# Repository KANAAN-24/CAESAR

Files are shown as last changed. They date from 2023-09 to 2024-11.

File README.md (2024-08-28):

# Introduction #

We are the Kanaan team from the Qabatya Directorate of Education of the State of Palestine.
We designed, assembled and programmed the robot, which we called Caesar, to perform the tasks and performance required in preparation for participation in the World Robotics Olympiad (WRO) competition.

# Team members #

Coach's name: Ahmed Mazid Al-Bazour ,
Email: ahmadbzoor48@gmail.com
1) Student name: Hisham Omar Qalalwa ,
Email: hishamqalalwal@gmail.com
2) Student name: Majd Khaled Azzam ,
Email: majoodazzam2@gmail.com

# Content #

* `t-photos` contains 2 photos of the team (an official one and one funny photo with all team members).
* `v-photos` contains 7 photos of the vehicle (from every side, from top and bottom).
* `video` contains the video.md file with the link to a video where driving demonstration exists.
* `schemes` Includes JPEG and PDF diagrams illustrating all car components electromechanic (electronic and others), and their connections.
* `src` contains codes of control software for all components which were programmed to participate in the competition.
* `models` They are files of designs 3D that were printed by two 3D printersTo produce car structure and
its items. 
* `Documentation` This volume covers robot construction, electronic components integration, and software algorithm Explanation about.
* `other` These files pertain to the work environment and work-related events.

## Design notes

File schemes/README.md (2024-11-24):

# Introduction #
Folder contains the electrical design schematics and the mechanic.

# Overview #
- `Main Diagram.jpg` Folder contains the electrical design schematic for the CAESAR Robot.
- `Mechanical Diagram.pdf` Folder contains design schematics the mechanic for the CAESAR Robot, as it is an open source design from the internet, we modified it and made the CAESAR Robot.

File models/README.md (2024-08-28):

# Introduction #
All of these designs were designed and printed by us, and all of them have been used.

# Overview #
+ `Battary` It contains two types of battery holder (the best was used) and its holder.
+ `Camera and Servo` It houses a servo motor holder connected to the steering wheel, a cover for the servo motor, and a camera holder positioned on top.
+ `chassis` It contains two pieces that are brought together to form the car's body and its supports.
+ `Level` A piece for the switch to convert the mode.
+ `Processing` It features a house-like piece that opens and closes with a screw for easy access, revealing a rectangular base for the ESP32 inside.
+ `Stearing` Contains string pieces.
+ `Team` An image of the team’s logo, its name, and a 3D design of the Palestinian keffiyeh.
+ `Ultrasonic` It contains an ultrasonic incubator and its covers.
+ `Wheel` Pieces to connect the wheels to the steering wheel.

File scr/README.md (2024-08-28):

# Introduction #
This directory contains code for control software which is used by the vehicle to participate in the competition and was developed by team KANAAN.

# Overview #
- `Obstacle Challenge Code` Codes for the stage two of the competition in which there are obstacles and The engines and other parts were programmed in C++ and we used Python for Artificial Intelligence.
- `Open Challenge Code` Codes for the first stage, where the engines and the rest of the parts were programmed in the C++ language.

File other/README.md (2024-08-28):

# Introduction #
It contains pictures and files related to work and some situations.

# Overview #
- `3D printers` It contains two pictures of the two 3D printers and their room.
- `Build` The Build contains the step to build a game mat.
- `CAESAR` It contains a file explaining the pieces.
- `Failed` It contains images of 3D designs with errors.
- `KANAAN` It contains a our team logo KANAAN.

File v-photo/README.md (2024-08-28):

# Introduction #
Folder contains photos of the CAESAR from all required directions.

# Overview #
- `Back Side.jpg` Ultrasonic box with battery incubator.
- `Down Side.jpg` A 3D printed base supports the car's steering wheel and various components above it.
- `Front Side.jpg` Ultrasonic incubators feature a wheel carrier to prevent collisions with the mat's outer frame and a camera mount on a 3D cover for the servo motor.
- `Left Side.jpg` Two incubators for controllers and other electronic parts.
- `Right Side.jpg` Incubators for electronic parts with a light indicating the robot's mode at what stage.
- `Top Side1.jpg` Operating button with 3D electronic parts carrier.

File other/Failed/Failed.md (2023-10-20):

# Introduction #
This image is of a 3D design that we printed, but it failed due to a support glitch

# Content #
failed2

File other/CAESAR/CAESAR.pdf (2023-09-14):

# Stages of making a CAESAR

## ENG.AHMAD

## HISHAM

## MAJD

## KANAAN Team

# Introduction

WRO Future Engineers -Selft Driving car
selft driving car

When we talk about competitions that are concerned with the field of robotics, we must talk about The World Robot Olympiad (WRO) , which was launched for the youth category. China, Japan and Singapore, and these four countries are the founding countries of this Olympiad (now known as the WRO Advisory Board).

# Problems

## Our Competition:

We are competing in this competition in the Future Engineers category It revolves around designing a self-driving robot that can overcome the obstacles and problems it encounters in the least possible time, based on artificial intelligence and machine learning.

## Contest idea:

The environment of this competition consists of a circuit surrounded by an external wall, inside which there is an internal wall. As for the competition, it consists of one stage in which the robot runs at a rate of 3 laps that it must complete in .3 minutes as a maximum

## Stage 1:

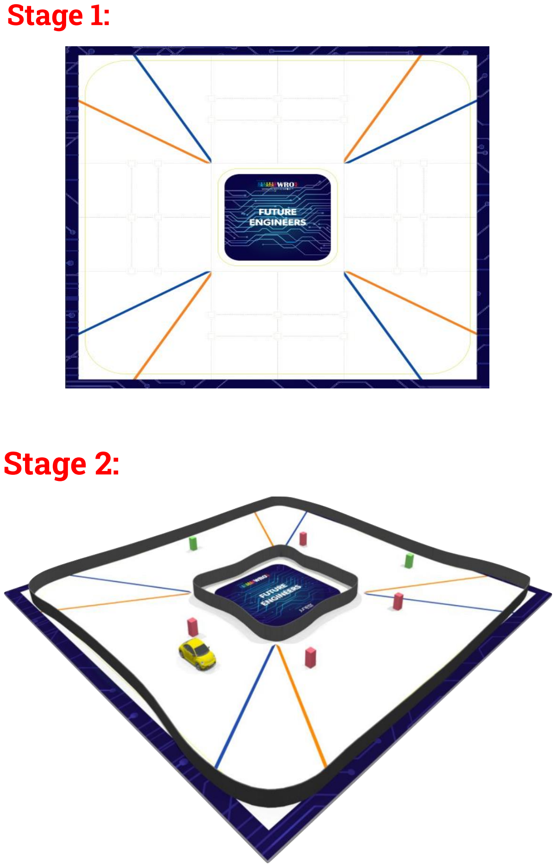
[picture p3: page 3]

# Stage 2:

# Hypotheses

During our work and the manufacture of the robot, we encountered many problems, and it is normal for such matters to happen in this field. They must be resolved with patience, effort, research, and the use of time to find an accurate solution.

## Hypotheses and questions:

How to identify the appropriate electronics and employ them properly?

How can machine learning be employed in the work of a robot?

How can you complete the race and avoid mistakes?

How can a software algorithm be found to make the performance professional?

How to find solutions to all possible possibilities?

## can the robot turn the path and overtake the obstacle under the rules it adheres to?

# Methodology

The design phase of the robot was divided into 2 parts namely:

## 1. Hardware and 3D design 2. Software

First, the electronics were selected according to the "WRO" competition.

Secondly, we start creating 3D designs to be placed on most electronic pieces to install or otherwise.

Thirdly, we start installing the 3D designs of electronics on the robot and conducting a preliminary test for it.

Finally, we start writing the software code and employing these electronics in it.

# The Electronics

## Use Electronics:

- ESP32 DEVKIT V1
- Raspberry Pi 4
- L298N Motor Driver
- MPU6050
- DC voltage Buck
- DC Encoder Motor
- Servo Motor
- Battery
- Ultrasonic Distance sensor x(4)
- Wires
- Wheels

## Raspberry Pi 4 Computer:

Processor: Broadcom BCM2711, quad-core Cortex A72 (ARM v8)

64-bit SoC @ 1.5GHz.

Memory: 1GB, 2GB or 4GB LPDDR4

Connectivity: 2.4 GHz and 5.0 GHz IEEE

802.11b/g/n/ac wireless LAN, Gigabit Ethernet

2 × USB 3.0 ports

2 × USB 2.0 ports

GPIO: Standard 40-pin GPIO header.

Input power: 5V DC via USB-C connector (minimum3A) 5V DC via

GPIO header (minimum 3A ) Power over Ethernet (PoE)–enabled

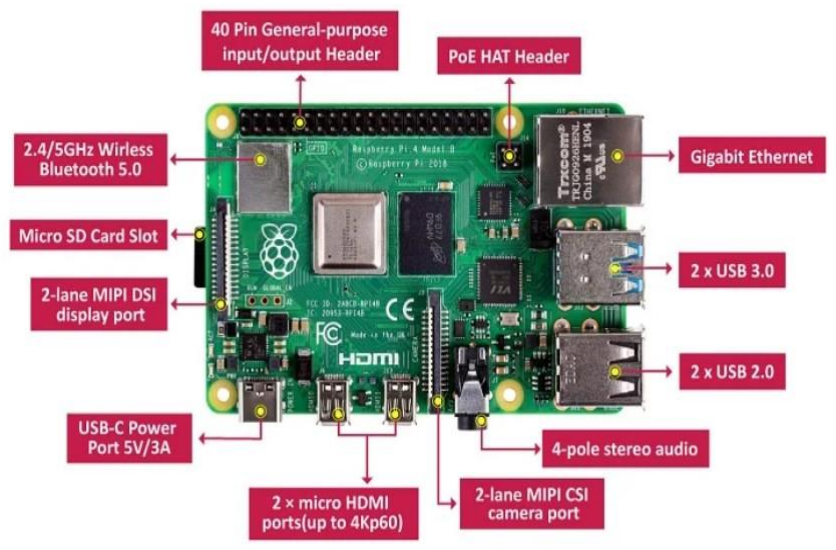
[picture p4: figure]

## ESP32 DEVKIT V1:

INPUT VOLTAGE (LIMIT): 3.3v

Microcontroller: System-on-Chip

Flash Memory: 4MB

Analog In Pin: 18

Digital I/O Pins: 28

Weight: 30g

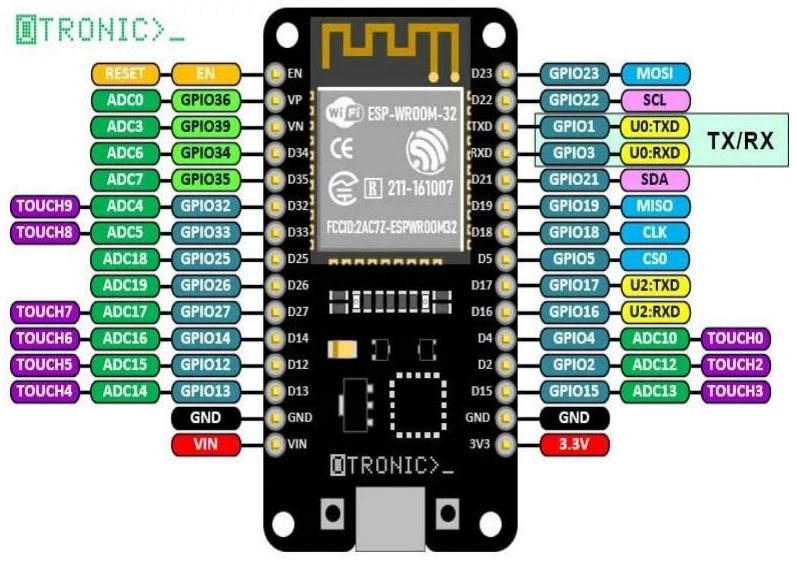
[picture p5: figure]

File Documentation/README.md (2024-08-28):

# Introduction #
This folder contains files that explain, from A to Z, the hardware, software, and three-dimensional design of the robot and their integration with each other.

# Overview #
- `Robot building instruction` Explaining 3D designs and the function of each.
- `Robot design description` Explanation of electronic parts and their integration with each other and with 3D designs.
- `Threads on code` Idea files and code explanation with key lines.

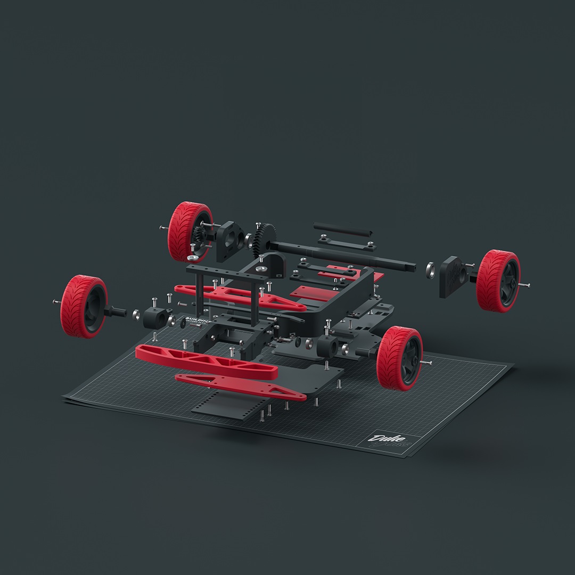
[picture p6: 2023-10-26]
schemes/Mechanical Diagram.jpg

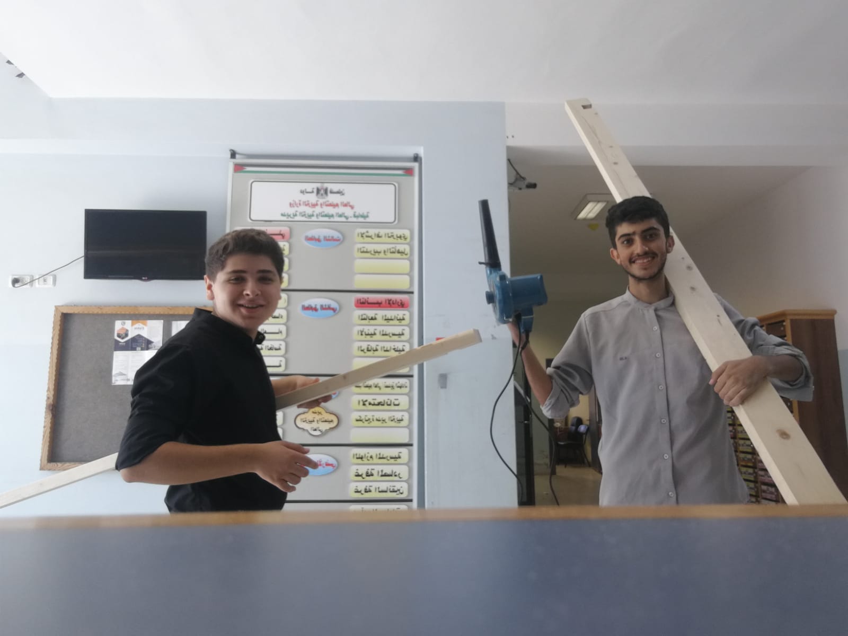
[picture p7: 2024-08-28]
t-photo/Funny 2.jpg

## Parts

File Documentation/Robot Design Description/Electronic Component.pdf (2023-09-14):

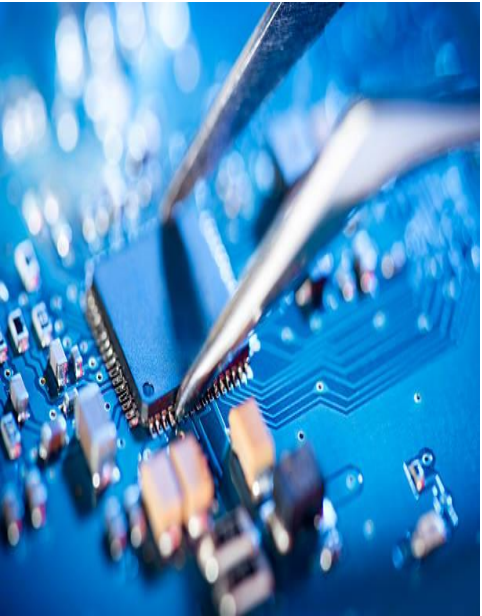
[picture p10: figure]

# Electronic Parts

# KANAAN TEAM

# Content

- Main Diagram
- ESP32 DEVKIT V1
- Raspberry Pi 4
- L298N Motor Driver
- MPU6050
- DC voltage Buck
- DC Encoder Motor
- Servo Motor
- Battery

# Main Diagram

The electronic diagram illustrates the interconnection mechanism between the controllers and how the ESP32 controller is linked to the Ultrasonic sensors and motor driver. The motor driver is responsible for governing both the DC motor and the servo.

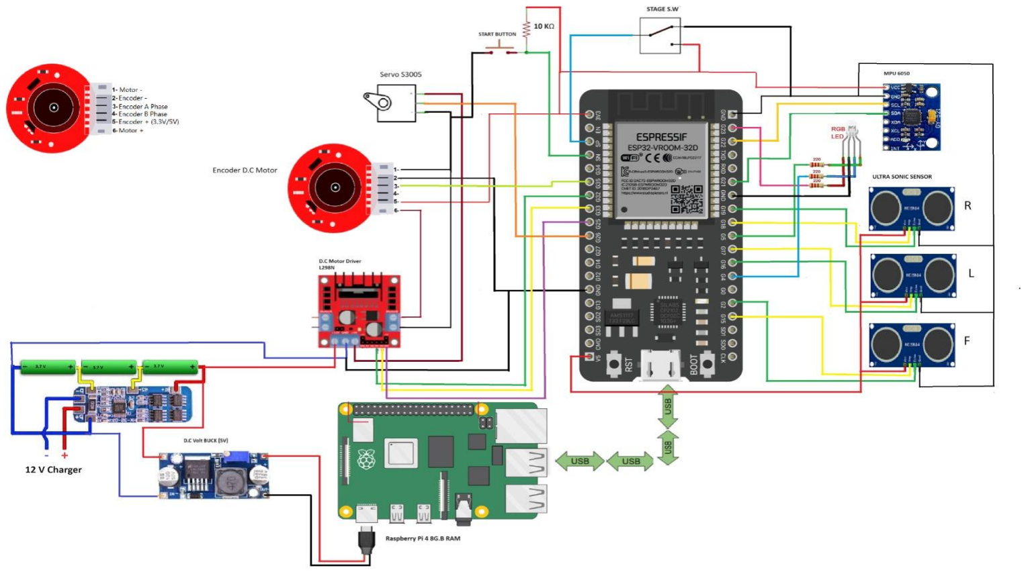
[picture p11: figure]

# ESP32 DEVKIT V1

ESP32 DEVKIT V1 microcontroller assumes a central role in orchestrating various electronic components through the following processes:

Initially, it commands the servo motor and DC motor by transmitting precise directives to the motor driver.

Subsequently, it gathers distance measurements from the front, back, and side ultrasonic sensors.

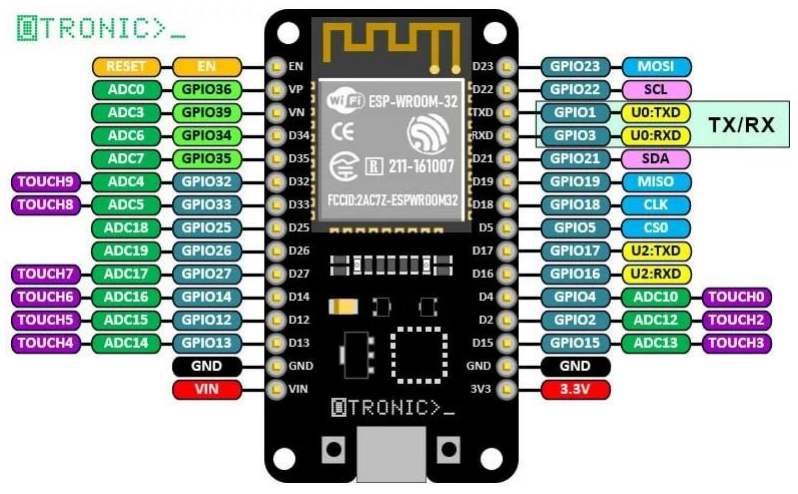
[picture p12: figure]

Furthermore, it governs the RGB LEDs, enabling dynamic manipulation of their color output.

Lastly, it detects input from the push button to initiate the vehicle's functions. It is imperative to note that the ESP32 DEVKIT V1 has been selected over the Arduino Nano, as it provides distinct ports for each function without necessitating multiplexing. This configuration optimizes the utilization of PWM (Pulse Width Modulation) capabilities, enhancing overall efficiency. Additionally, the system monitors the switch input to facilitate seamless code adjustments.

# Raspberry Pi 4

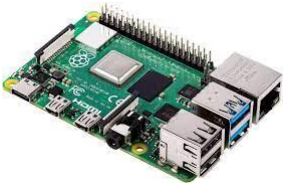
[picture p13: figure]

Firstly, it is utilized to program the ESP32 microcontroller. Secondly, it handles the task of reading and processing data from the camera, utilizing the Python language integrated into its operating system. Lastly, it is responsible for transmitting commands based on the camera's perception of pillars and their respective colors to the ESP32

controller.

# L298N Motor Driver

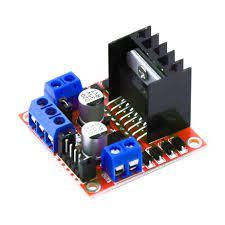
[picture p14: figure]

The motor driver serves a dual purpose, enabling both speed control for the DC motor and facilitating forward and backward motion, while also governing the movement of the servo motor.

# MPU6050

The MPU6050 is a popular sensor module that combines a 3-axis gyroscope and a 3-axis accelerometer into a single package. It is commonly used in projects involving motion tracking and orientation sensing. In our program, we integrated the MPU6050 to precisely calculate the rotation angles.

This sensor provides crucial data about the device's orientation and movement. The gyroscope measures angular velocity, which helps determine the rate of rotation around each axis. Meanwhile, the accelerometer measures linear acceleration, which is used to calculate the orientation of the device relative to the Earth's gravitational field.

By carefully processing the data from the MPU6050, we were
able to obtain accurate and real-time information about the

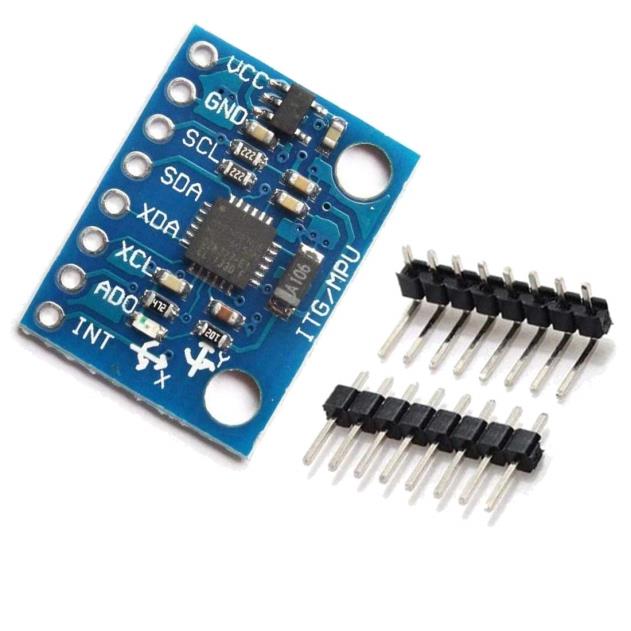
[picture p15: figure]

device's orientation in space. This information was then utilized for various purposes within our program, enhancing its functionality and enabling it to respond dynamically to changes in orientation. This capability proved particularly valuable in applications where precise orientation tracking was essential for proper operation.

# Ultrasonic Sensors

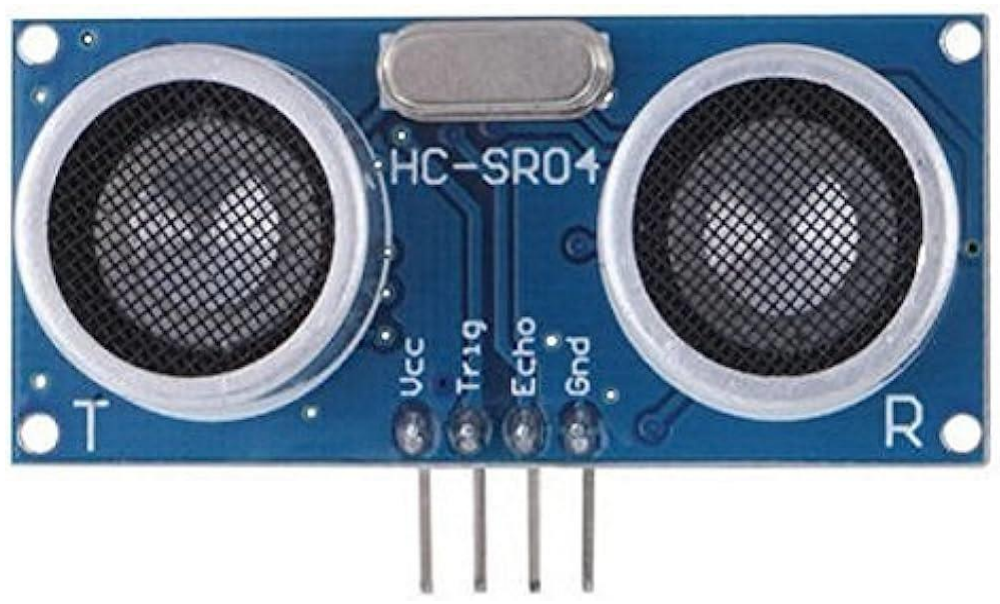
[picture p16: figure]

A trio of sensors is employed, with one positioned at the front and two on the sides. These ultrasonic sensors play a crucial role in determining distances and the direction of the vehicle's movement, along with providing valuable
insights into other pertinent aspects.

# Battery

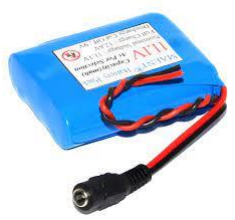
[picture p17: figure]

The vehicle relies on a battery to supply essential power. This battery configuration comprises three lithium batteries interconnected in series.

# DC voltage Buck


The core of this circuit design lies in the incorporation of a DC voltage Buck. Specifically engineered for voltage regulation, the DC voltage Buck plays a pivotal role in mitigating the high voltage output from the 12-volt batteries. Its primary function is to efficiently step down the voltage, ensuring that the electronic components receive a stable and appropriate voltage level for optimal performance.

# DC Encoder Motor


The DC motor is physically linked to the rear wheels, enabling the vehicle's motion.

The reason for using an Encoder is to monitor the motor's direction and movement, which proves instrumental in controlling the overall movement of the vehicle.

# Servo Motor


The servo motor assumes the responsibility of directing the vehicle by manipulating the steering wheel.


# THANK YOU

# KANAAN TEAM

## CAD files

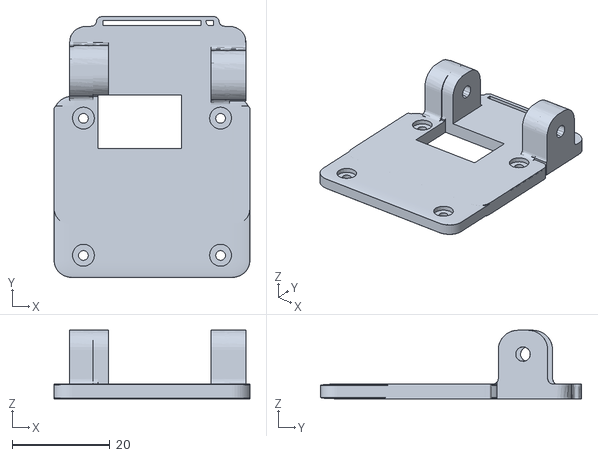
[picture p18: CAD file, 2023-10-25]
models/3D Printing Designs/Camera and Servo/cam stand.stl
40.0 x 53.3 x 14.0

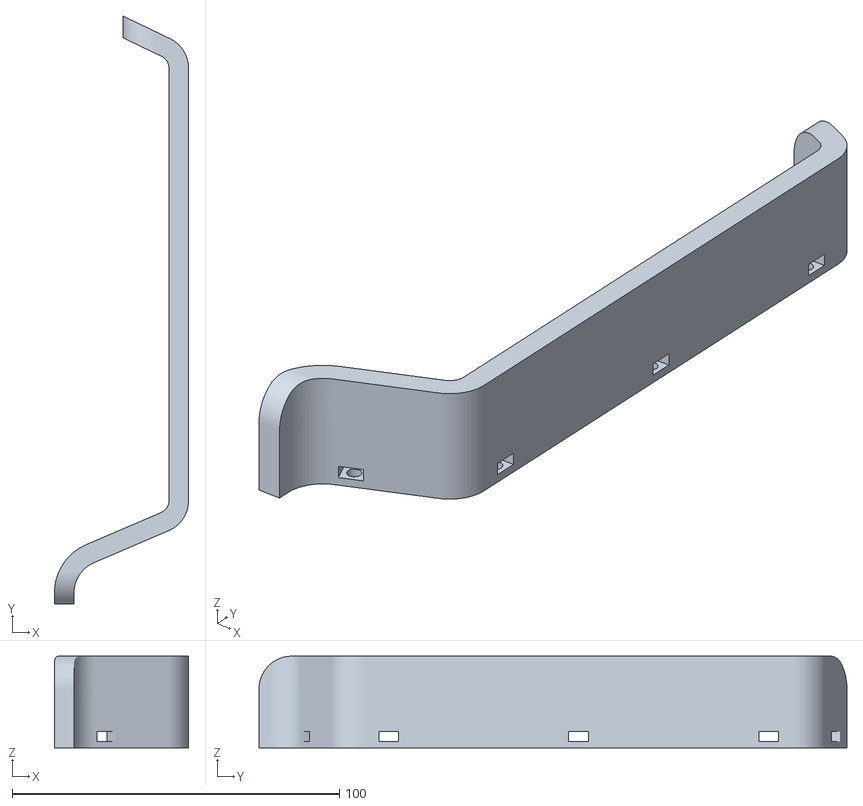
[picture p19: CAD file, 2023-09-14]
models/3D Printing Designs/Chassis/Body_L.stl
41.0 x 179.6 x 28.0

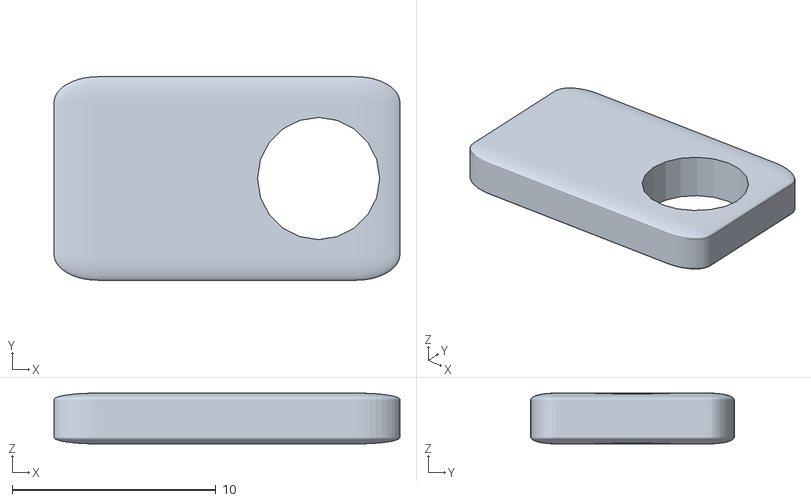
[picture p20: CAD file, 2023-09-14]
models/3D Printing Designs/Level/LevelKeyholder.stl
17.0 x 10.0 x 2.50

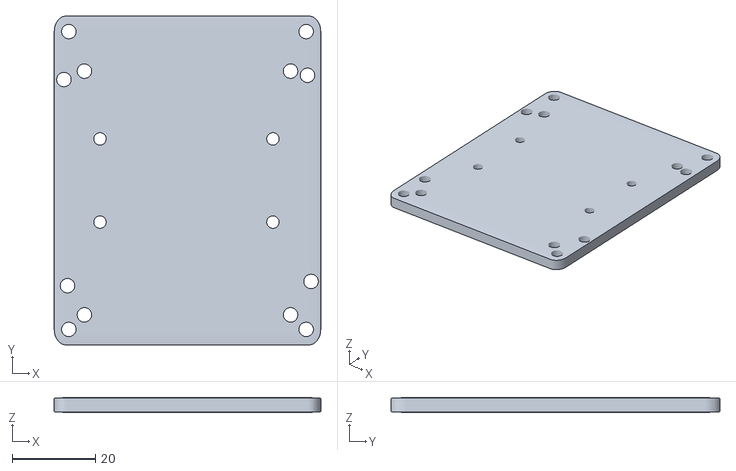
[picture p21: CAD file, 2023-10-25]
models/3D Printing Designs/Processing/ESP32HolderF (2).stl
64.0 x 79.0 x 3.50

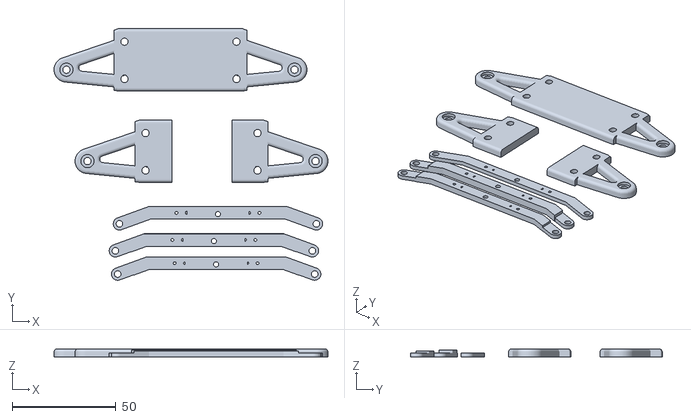
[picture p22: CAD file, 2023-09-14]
models/3D Printing Designs/Stearing/small stearing.stl
132.1 x 121.3 x 4.00

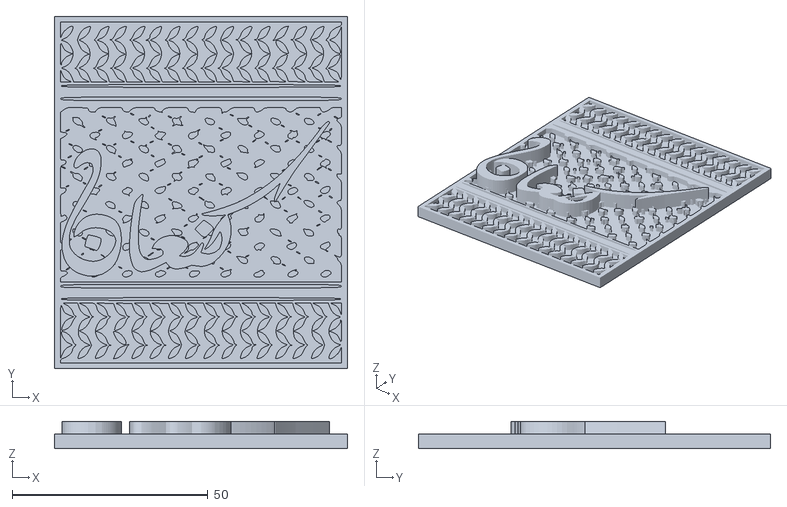
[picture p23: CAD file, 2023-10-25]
models/3D Printing Designs/Team/Kanaan_Back (1).stl
75.0 x 90.0 x 7.00

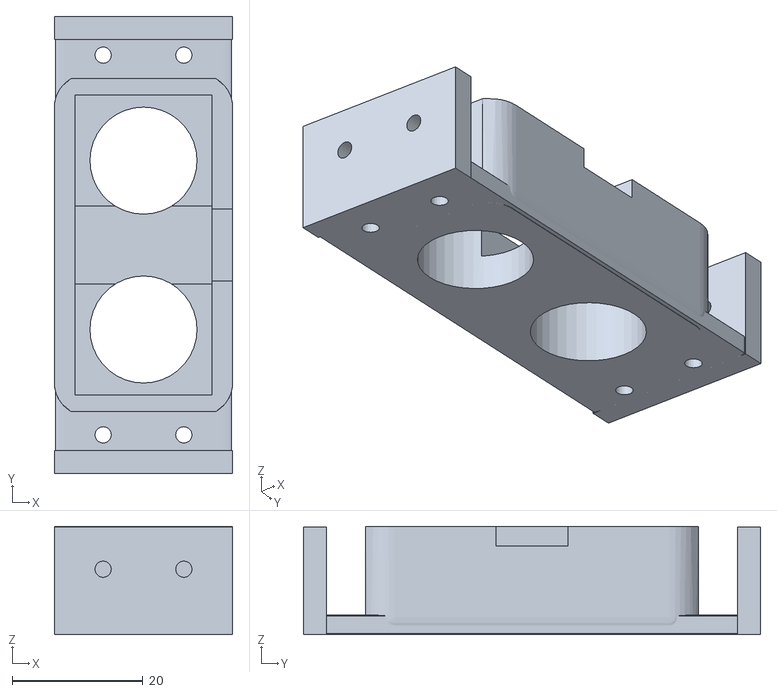
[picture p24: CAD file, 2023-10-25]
models/3D Printing Designs/Ultrasonic/FinalUltra (8).stl
27.3 x 70.0 x 16.5

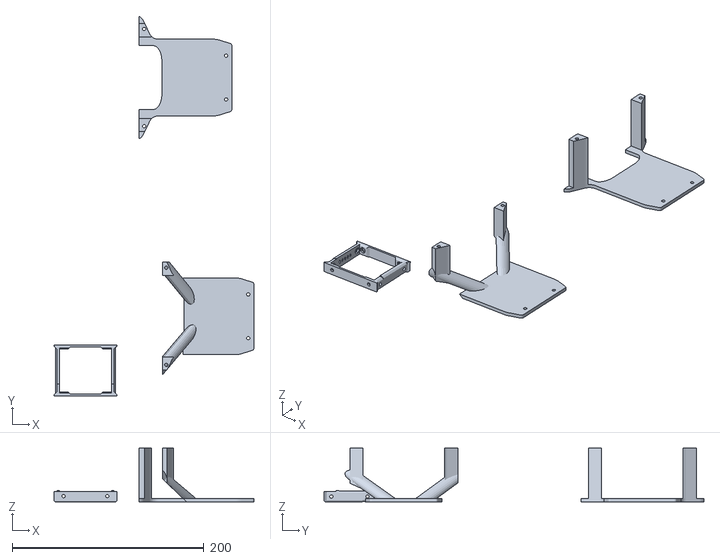
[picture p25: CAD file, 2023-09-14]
models/3D Printing Designs/Battary/Battary Holder1.stl
208.6 x 395.9 x 56.1

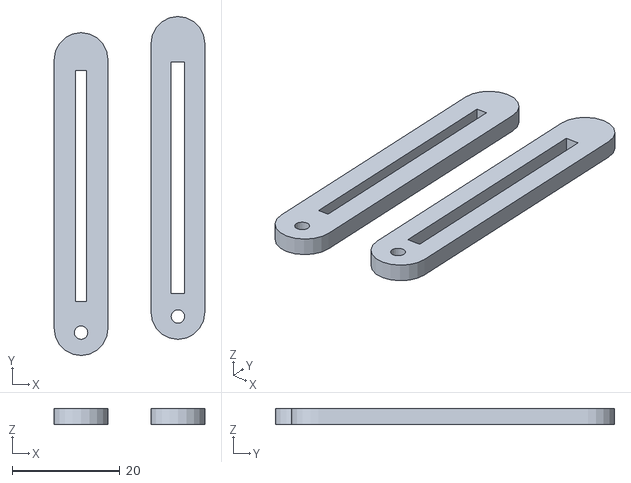
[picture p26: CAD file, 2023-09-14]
models/3D Printing Designs/Camera and Servo/ServoSlider2.stl
28.0 x 63.0 x 3.00

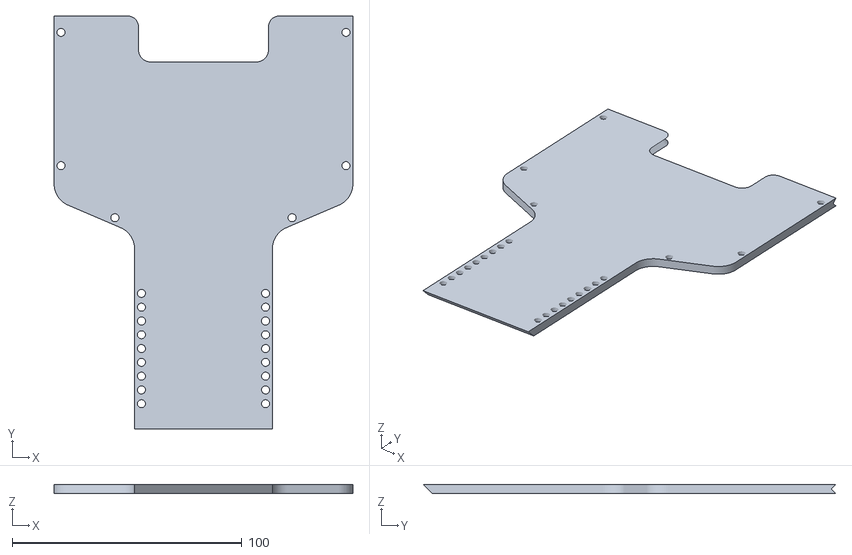
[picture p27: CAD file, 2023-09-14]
models/3D Printing Designs/Chassis/Chassis_1.stl
130.0 x 179.7 x 4.00

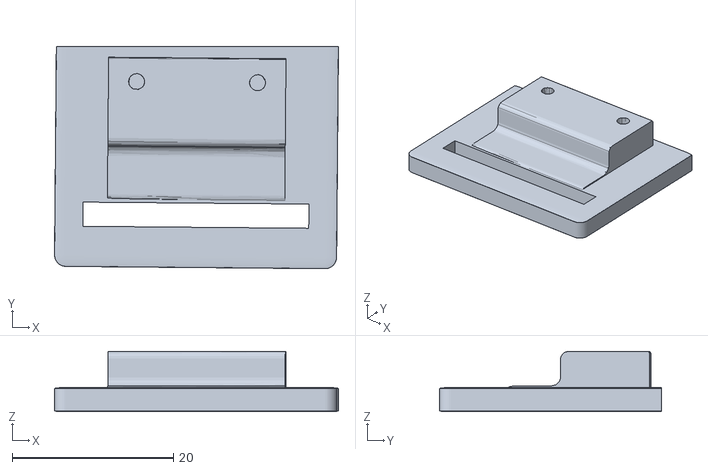
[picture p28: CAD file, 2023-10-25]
models/3D Printing Designs/Processing/MPU.stl
35.2 x 27.6 x 7.50

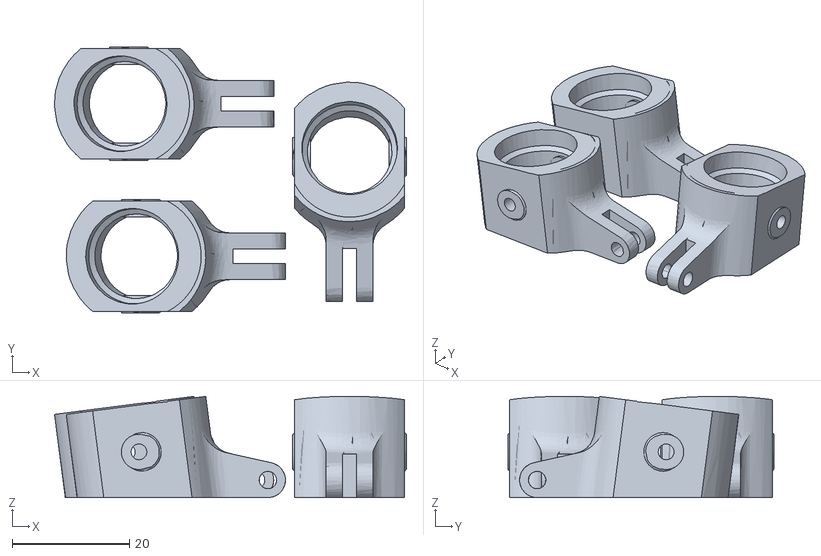
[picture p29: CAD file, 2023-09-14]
models/3D Printing Designs/Stearing/STEERINGWEELADAPTER.stl
60.0 x 45.4 x 17.3

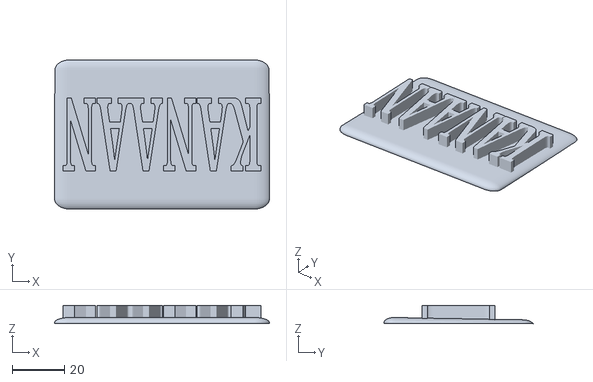
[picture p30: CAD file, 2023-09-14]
models/3D Printing Designs/Team/TeamName (1).stl
82.0 x 56.8 x 7.00

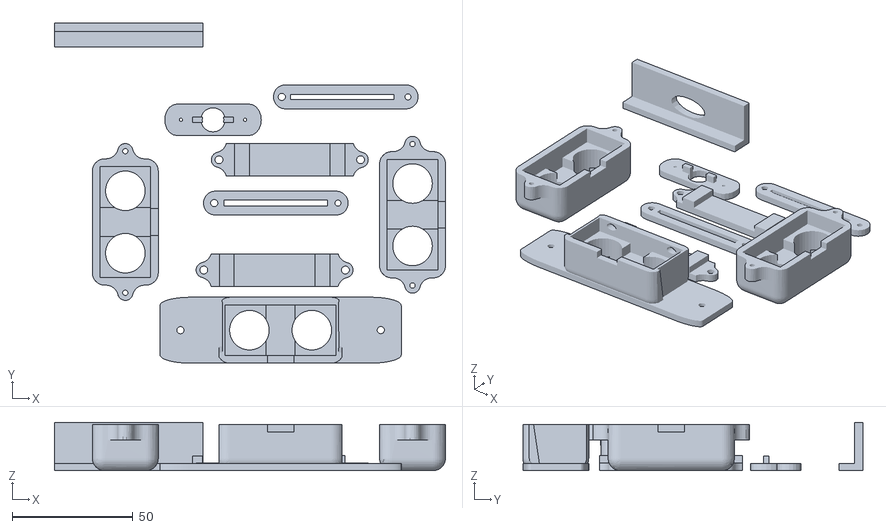
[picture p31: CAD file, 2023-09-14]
models/3D Printing Designs/Ultrasonic/ultrasonicHolder.stl
162.0 x 141.0 x 20.0

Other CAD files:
models/3D Printing Designs/Battary/battary holder.stl
models/3D Printing Designs/Camera and Servo/Servo holder.stl
models/3D Printing Designs/Chassis/Chassis_2.stl
models/3D Printing Designs/Processing/processing (1).stl
models/3D Printing Designs/Battary/battary holder (2).stl
models/3D Printing Designs/Camera and Servo/Servo holder (2).stl
models/3D Printing Designs/Camera and Servo/ServoSlider.stl
models/3D Printing Designs/Camera and Servo/Smooth Waasa.stl
models/3D Printing Designs/Camera and Servo/cameraStand and servocover.stl
models/3D Printing Designs/Chassis/Case_Holder.stl
models/3D Printing Designs/Chassis/Chassis_2_v2.stl
models/3D Printing Designs/Processing/Rear_Flex_2.stl
models/3D Printing Designs/Team/TeamLogo.stl
models/3D Printing Designs/Team/kofeia.stl
models/3D Printing Designs/Ultrasonic/ultraBack.stl
models/3D Printing Designs/Wheel/Basic_Wheel_01_Nut.stl
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

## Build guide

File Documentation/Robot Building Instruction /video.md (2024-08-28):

## Assembling CAESAR ##

https://youtu.be/CFM_wHyjjro?si=B5Qv0K5pltAAQcLi

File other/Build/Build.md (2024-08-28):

Building Game Mat
====
I share with you a small moment from our workshop where we carved the wood to eliminate the distortions, then painted it black, dried it, and then pressed it for days so that no curvature occurred.

## Content ##
build

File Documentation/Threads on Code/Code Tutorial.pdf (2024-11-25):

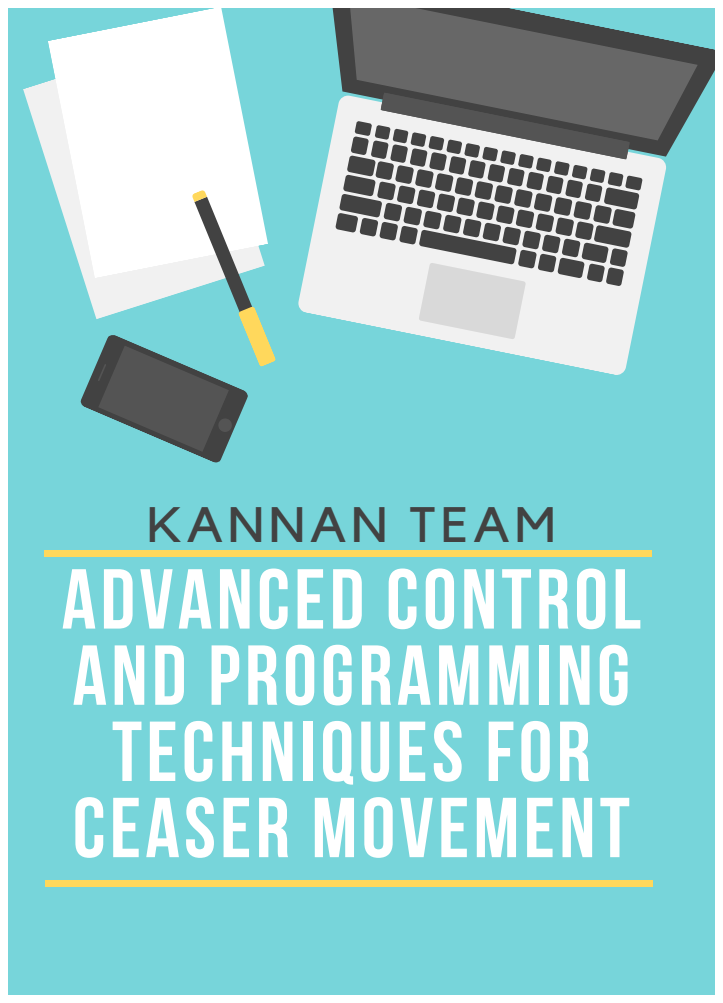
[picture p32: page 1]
ADVANCED CONTROL AND PROGRAMMING TECHNIQUES FOR CEASER MOVEMENT; KANNAN TEAM

## Table of Contents:

## 1. Introduction:

The Robot, named Caesar, employs two microcontrollers: Raspberry Pi and ESP32 DEVKIT V1. The ESP32 DEVKIT V1 is programmed within a Linux environment hosted on the Raspberry Pi. It establishes communication with the Raspberry Pi through a serial port. The designated platform for coding and uploading onto the ESP32 DEVKIT V1 is the Arduino IDE ARM version.

In this configuration, the ESP32 DEVKIT V1 microcontroller is programmed using the C++ language. Its functions encompass controlling the motor, steering wheel, and sensors (specifically, Ultrasonic). On the other hand, Python is employed for image processing on the Raspberry Pi. The program leverages appropriate libraries, including OpenCV, downloaded and configured to align with Python. This facilitates tasks such as image capture from the camera, clustering of red and green pillars, and the subsequent issuance of commands based on detected colors.

## 2. The Robot's Journey in Stage One:

In the initial stage of our project, the robot's primary task is to move autonomously, but without any pillars.

## 2.1 Deciphering Direction:

One of the challenges in this stage lay in developing an algorithm that allowed the robot to determine its direction, specifically whether it should move in a clockwise or counterclockwise direction.

Prior to the first turn, the robot operated in a state of directional uncertainty. To address this challenge, we incorporated ultrasonic sensors into our design. These sensors played a pivotal role in measuring the distance between the robot and its surroundings.

The algorithm we employed was ingeniously simple yet effective:

Ultrasonic Measurements: The robot utilized its ultrasonic sensors to measure the distance to objects in its vicinity.

Directional Indicators: Here's where the magic happened. Until the first turn was encountered, the robot remained clueless about its direction. However, it was equipped to make an informed decision when the time came.

If the left ultrasonic sensor registered a distance greater than 160 cm or zero (indicating more than 280cm meters of open space to the left), the robot inferred that it should proceed in a clockwise direction.

Conversely, if the right ultrasonic sensor measured a distance greater than 160 cm or zero (suggesting more than 280cm of open space to the right), the robot deduced that it should move counterclockwise.

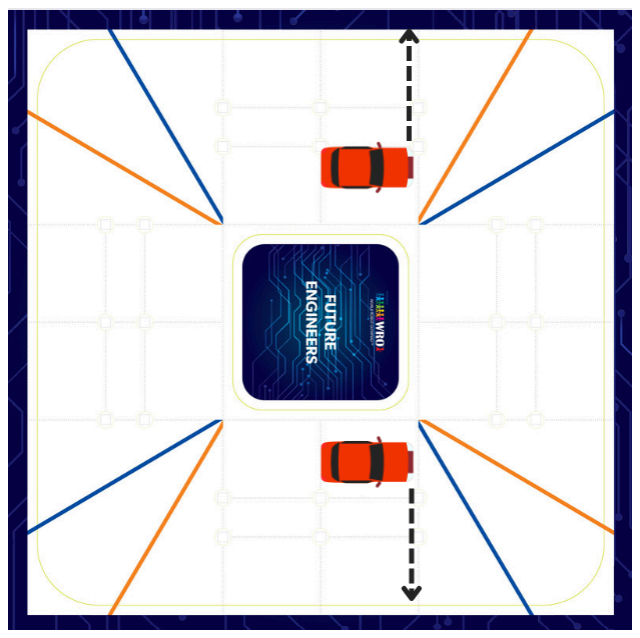
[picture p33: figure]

This ingenious algorithm ensured that the robot remained adaptive and selfaware. Until the moment of truth – the first turn – the robot's direction remained a mystery, but with ultrasonic measurement, it allowed him to decipher its path, reflecting the essence of autonomous navigation in this intriguing stage of our project.

## 2.2 How Our Robot Moves: The Algorithm in Action:

In our project, we implemented a PID (Proportional, Integral, Derivative) control system to ensure precise steering and movement of our robot. This system is a sophisticated control mechanism widely used in robotics and automation. Here's how we put it to work:

What is PID System:

The PID system is a feedback control loop that calculates and applies an error-correction value based on proportional, integral, and derivative terms. It helps to accurately maintain a desired set point or target.

Steering Control:

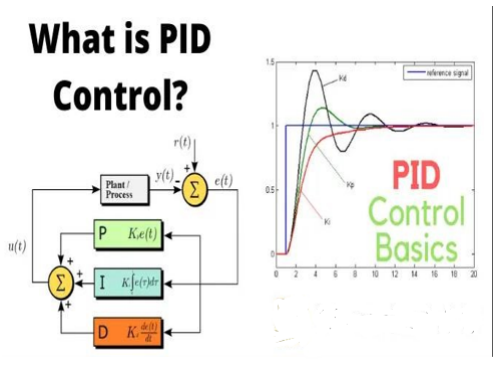
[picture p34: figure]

In our robot, we employed the PID system to govern the steering mechanism. Attaining the precise PID parameters, however, posed a substantial challenge. To simplify this endeavor, we devised a mobile application allowing us to directly input the PID values. This not only saved us considerable time but also spared us the repetitive task of manual adjustments on the laptop. Given the frequent necessity for PID tuning, this app emerged as an indispensable tool in guaranteeing optimal performance. For instance, setting the P gain too high could lead to overshooting, while setting it too low might result in sluggish responses from the robot.

Setting the Set Point:

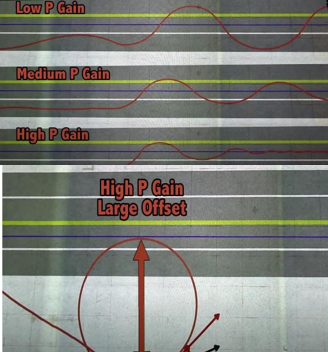
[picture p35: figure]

Until the first turn occurs, the robot operates with an undetermined direction. Once the first turn takes place, the set point for the PID system is determined based on the outer edge. For clockwise movement, the outer edge is on the left side, and for counterclockwise, it's on the right.

Determining Turns:

In each subsequent turn, a new set point is established, based on the outer edge. The robot assesses which side to turn based on the ultrasonic sensor readings. If one of the side ultrasonic sensors depending on his direction measures more than 120cm or zero (indicating a distance greater than 280 cm), and the forward ultrasonic sensor measures less than 95cm, the robot recognizes that a turn is necessary.

Utilizing the MPU6050 Sensor:

When executing turns, we leverage the MPU6050 sensor, which aids the robot in achieving precise 90-degree rotations.

Turn Counter:

To keep track of progress, we integrated a turn counter. This enables the robot to discern when it's approaching the final turn, ensuring a timely stop.

Completion of Stage One:

This process is reiterated with every turn until the completion of 12 turns, distributed evenly across the four rounds. At the conclusion of the 12th turn, the robot executes a controlled stop, marking the successful completion of stage one. This meticulous approach to movement and navigation lays a solid foundation for the subsequent stages of our project.

## 3. CAESAR In Stage Two (with obstacles):

If pillars are present, we've devised an algorithm that optimally positions the robot for traffic light interaction in Stage 2.

## 3.1 The Far Near Algorithem In Stage 2:

Overview:

The Far Near Algorithm, applied in Stage 2, enhances the robot's navigation by synchronizing the camera’s movement with the robot's steering for real-time obstacle detection. Previously, the ESP32 microcontroller received an array of three letters ('F' for Far, 'N' for Near) from the camera on the Raspberry Pi, where "Far" indicated areas close to the exterior wall or far from the internal square, and "Near" referred to areas near the inner square or far from the exterior wall. This information guided the robot’s path, allowing for efficient and precise movement around obstacles.

In the updated version, the array has been expanded to four spaces to include parallel parking detection. The fourth space provides information about parking in the current forward section:

'E' (Empty): No parking in this section.

This modification enables the robot to account for both obstacle avoidance and parallel parking requirements. By dynamically adjusting based on real-time data, the robot navigates complex environments and efficiently performs parallel parking after its designated rounds.

## 3.2 the First Part of the Algorithm (Learning Phase):

### 1. Initial Position Detection:

After pressing the start button, the robot determines its initial position using ultrasonic sensor measurements, stored in a variable called current_position.

Possible positions include:

'C' (Center): The robot is in the center of the game mat.

'F' (Far): The robot is near the exterior wall.

'N' (Near): The robot is far from the exterior wall and close to the inner square.

2.Movement to Determine Direction:

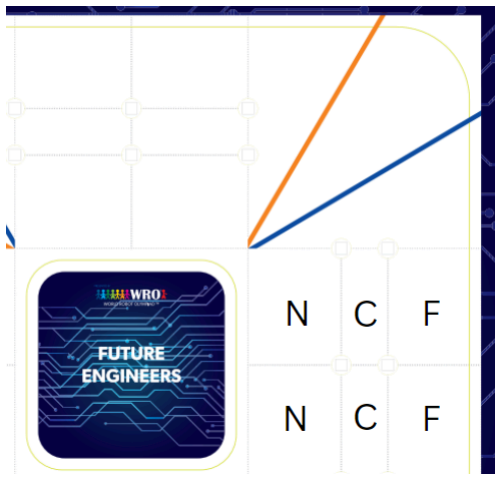
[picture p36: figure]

The robot moves straight until its front reaches the corner section, where it uses ultrasonic sensors to determine its direction (clockwise or counterclockwise). This direction detection is detailed in the Open Challenge algorithm.

3.Camera and Steering Synchronization:

The camera's movement is synchronized with the robot’s steering, a key feature of this algorithm. Once the robot detects its direction at the corner section, it adjusts its steering to

'H' (Head): A parallel parking spot is near the robot.
'T' (Tail): A parallel parking spot is far from the robot in the straight-forward section.

position the camera:

Counterclockwise Direction: The steering moves left, enabling the camera to capture the pillars on the straight forward section. The robot remains stationary for 3-4 seconds, allowing the camera, controlled by a Raspberry Pi, to process the surroundings.

Clockwise Direction: The steering moves right, enabling the camera to capture the pillars on the straight forward section. Similarly, the robot stays stationary while the camera captures the environment.

During this stationary period: The camera captures images to identify the positions of red and green pillars. The results are stored in an array of three letters ('N' for near, 'F' for far and 'E' for empty), guiding the robot’s movement to avoid obstacles:

Counterclockwise Movement:

Seeing a green pillar: The robot should move near ('N'), staying close to the inner square to avoid the pillar on the left.

Seeing a red pillar: The robot should move far ('F'), maintaining a distance from the inner square to avoid the pillar on the right.

Clockwise Movement:

Seeing a green pillar: The robot should move far ('F'), staying away from the inner square to avoid the pillar on the left.

Seeing a red pillar: The robot should move near ('N'), staying close to the inner square to avoid the pillar on the right.

4.Navigating to the Next Position :

The robot uses the information stored in current_position and next_position to determine its subsequent movements. For instance, if current_position is 'C' and next_position is 'F', the robot executes a maneuver aligned with its programmed instructions to move to the 'F' position.( note that C cab be just in the first round)

## 3.2 Between Obstacles Algorithm:

The Between Obstacles Algorithm manages the robot’s movement between identified obstacles using the data from the learning phase:

1.Continuing in the Same Position (F to F or N to N):

The robot moves straight ahead using PID control without altering its orientation. This ensures it maintains a steady path when consecutive positions in the array are the same.

2.Transitioning from Far to Near (F to N):

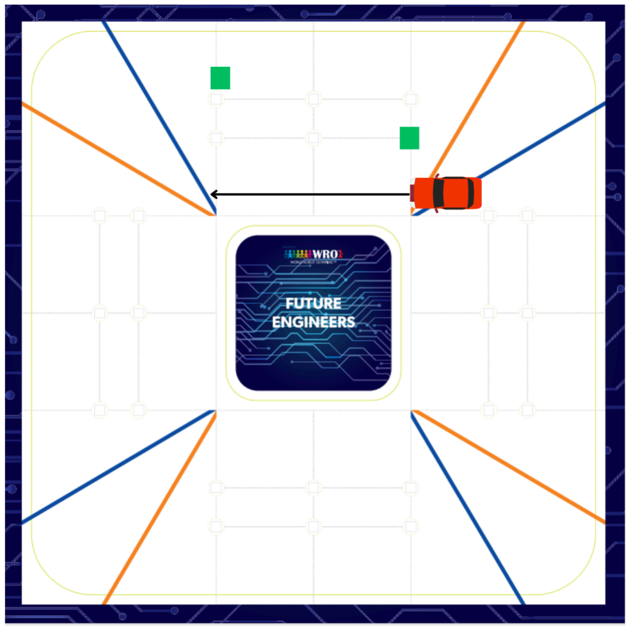
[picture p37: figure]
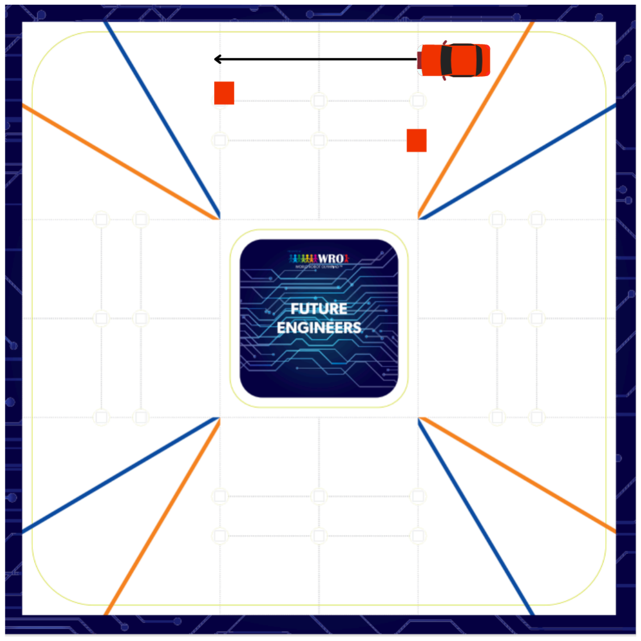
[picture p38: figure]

When the robot needs to shift from a far to a near position, it performs a series of calculated movements and turns. This involves adjusting the steering angles and speed to navigate closer to the inner square, avoiding obstacles effectively.

3.Transitioning from Near to Far (N to F):

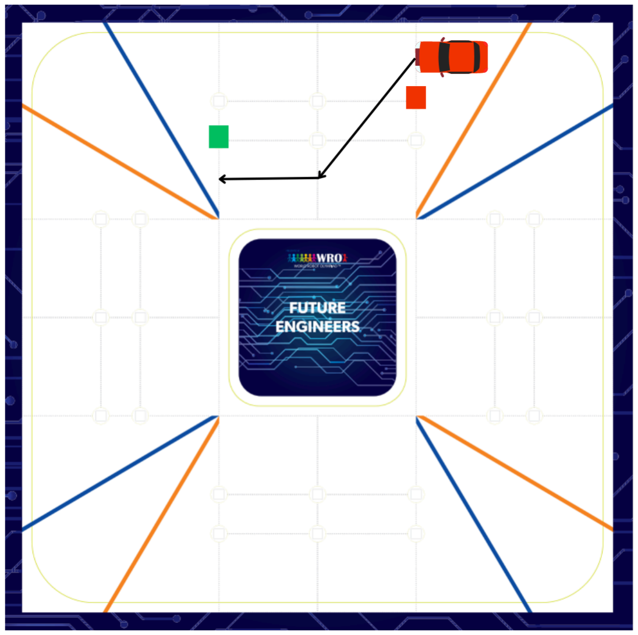
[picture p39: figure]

In the opposite scenario, the robot adjusts its path to move away from the inner square. It uses a precise sequence of movements, steering adjustments, and speed control to ensure a smooth transition to a far position.

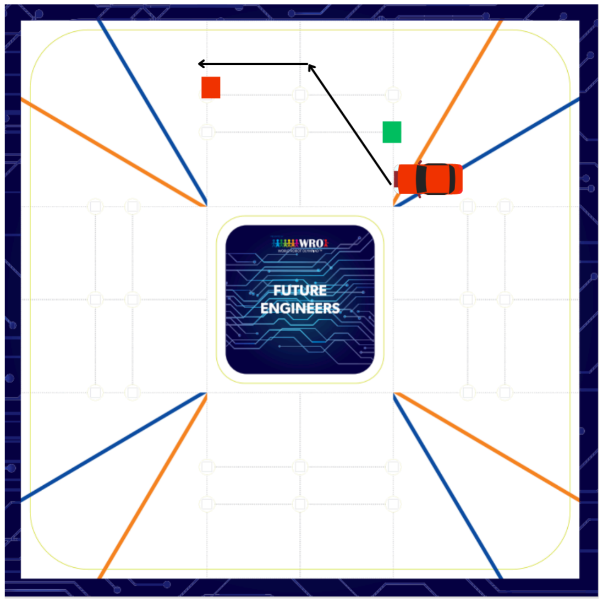
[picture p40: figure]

4.Transitioning from Far to Near to Far (F to N to F):

The robot initially moves from a far to a near position, navigating closer to the inner square to avoid obstacles on the far side. After this, it transitions back to a far position, moving away from the inner square. This sequence ensures that the robot efficiently avoids obstacles on both sides while maintaining a smooth path.

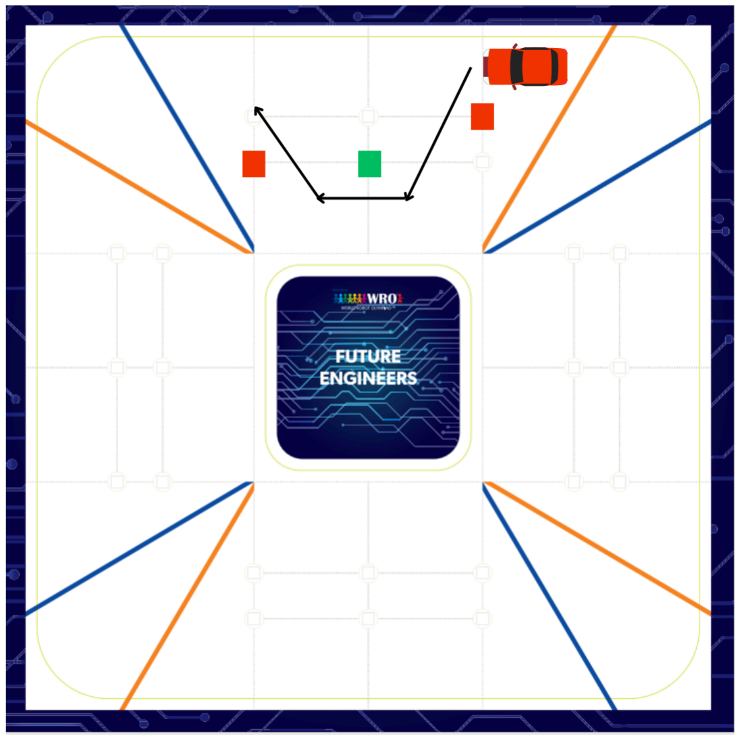
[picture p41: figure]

5.Transitioning from Near to Far to Near (N to F to N):

The robot moves away from the inner square (near to far), then transitions back to a near position to remain close to the inner square. This maneuver helps the robot effectively navigate areas with alternating obstacles, ensuring safe and efficient movement.

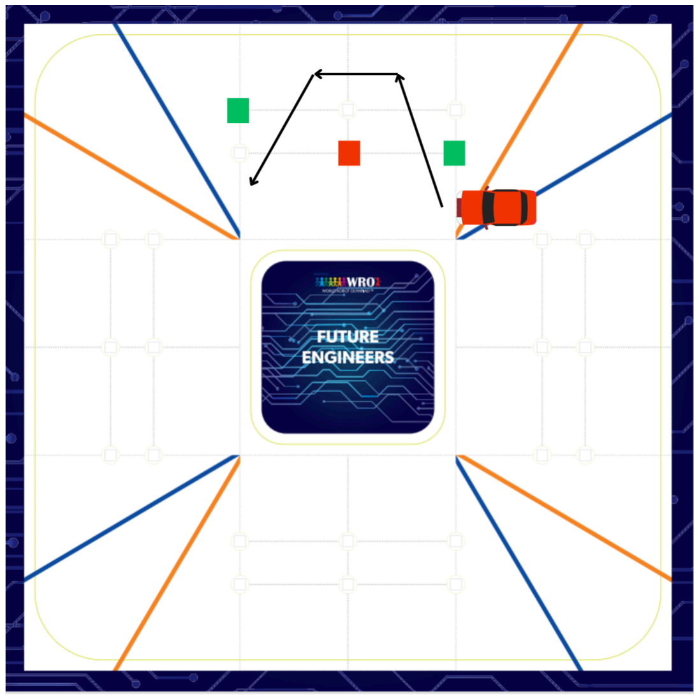
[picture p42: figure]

## 3.3 Parallel Parking Logic:

1.Determining Additional Rounds:

After completing the standard 12 rounds, the robot evaluates the arrays to identify the parking section:

c. Example: If the parking spot is in the second forward section ([F, F, N, H]), the robot performs 12 + 2 = 14 rounds before initiating parking.

2.Executing the Parallel Parking Maneuver:

After completing the additional rounds, the robot initiates the parallel parking maneuver based on the detected spot ('H' or 'T'). The process includes the following steps:

## 3.4 U-Turn Algorithm:

The U-turn algorithm is employed when the robot needs to reverse direction. To navigate obstacles after making a U-turn, the robot manipulates the array of detected positions:

a. The forward section with parking is the one where the fourth space in the array is either 'H' or 'T'.
b. The robot adds the number of this forward section (1–4) to the 12 rounds to determine the total number of rounds.
a. Step 1: Positioning for Parking:
The robot reverses by 90 degrees, aligning itself perpendicular to the parking space.
If the parking spot is 'H' (Head, close to the robot), it adjusts its position minimally before reversing.
If the parking spot is 'T' (Tail, far from the robot), it adjusts its position further before reversing.
b. Step 2: Entering the Parking Space
The robot moves straight into the parking space, using a dedicated parking camera (separate from the color detection camera).
The parking camera employs a PID control system to keep the robot centered between the two wooden barriers of the parking space.
The middle point between the two barriers is the set point for the PID control.
c. Step 3: Final Alignment Using Ultrasonic Sensors
Once the robot is between the barriers, it switches to readings from ultrasonic sensors. The ultrasonic sensors guide the robot using PID control to ensure precise alignment within the parking space.
The robot continues this process until it is fully parked inside the designated area.

1.Flip the Array: The sequence of detected positions is flipped. For example, an array of ['N', 'N', 'F'] becomes ['F', 'N', 'N'].

2.Reverse the Letters: After flipping, each letter in the array is reversed to reflect the new orientation. Thus, the flipped array ['F', 'N', 'N', 'H'] changes to ['N', 'F', 'F', 'T'].

This transformation ensures that the robot correctly interprets the environment and continues to avoid obstacles effectively even after reversing direction. By systematically flipping and reversing the detection array, the robot adapts its path dynamically to maintain efficient navigation throughout the course.

3.Adjust Additional Rounds:

This ensures that the robot adapts to the new direction and efficiently navigates to the parking spot after the U-turn.

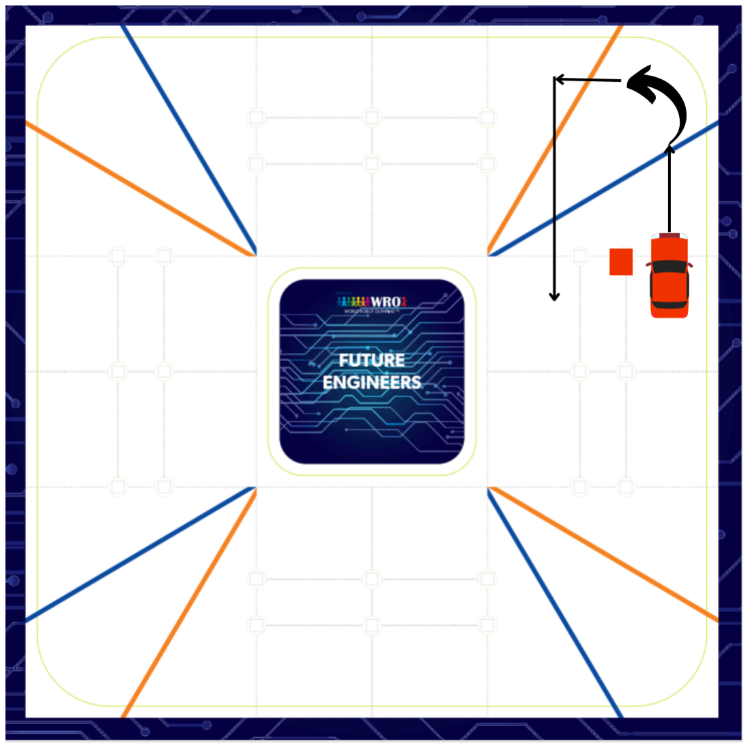
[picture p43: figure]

## 3.5 The Flowchart For The Far Near Algorithem:

Adjust the number of additional rounds for parallel parking based on the new direction:
3 additional rounds become 1.
1 additional round becomes 3.
2 additional rounds remain unchanged.

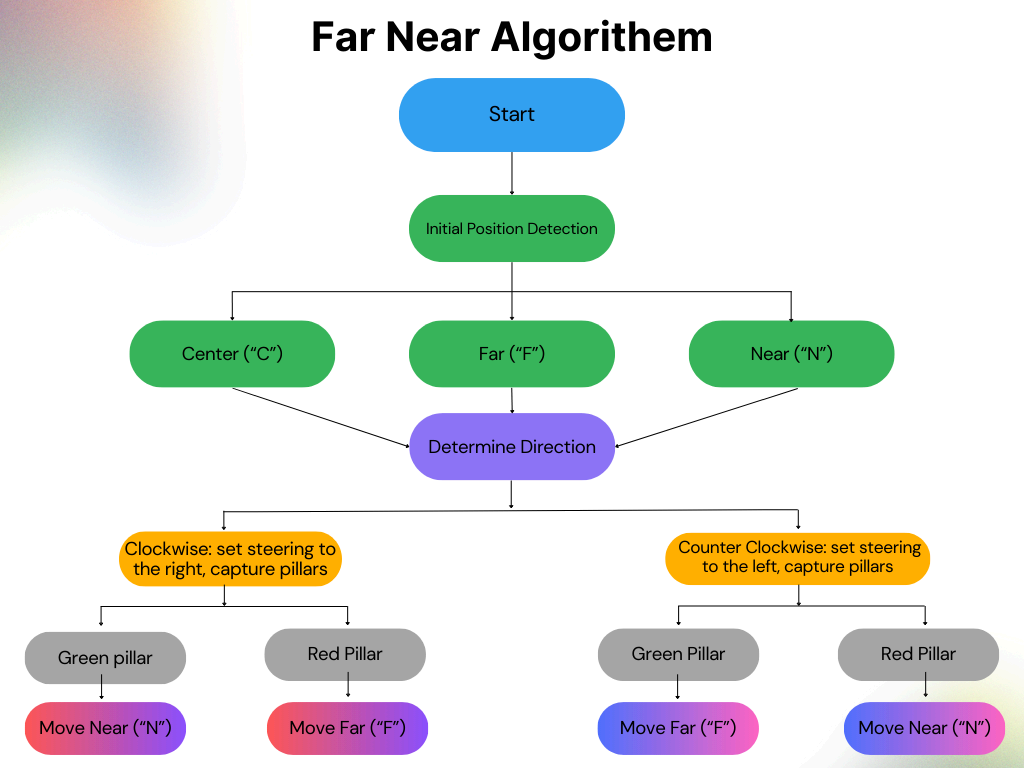
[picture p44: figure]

## 3.6 Summary:

The Far Near Algorithm, including the initial learning phase, the Between Obstacles Algorithm, and the U-turn Algorithm, enables the robot to navigate complex environments by synchronizing camera movements with steering, processing real-time data to adjust its path, and executing efficient maneuvers to avoid obstacles. This comprehensive approach ensures the robot can handle varying scenarios effectively, making it an optimal solution for precise and safe navigation in competitive settings.

## 4.DC Encoder:

In our car, we utilized a 130 RPM encoder for smooth and high-performance operation. Using the encoder, we found that each cm equals to 20 pulses in the encoder.

Hence, we have an equation that establishes a connection between the distance covered and the count of pulses:

## X(pulses) = cm*20

## 5.Camera coding:

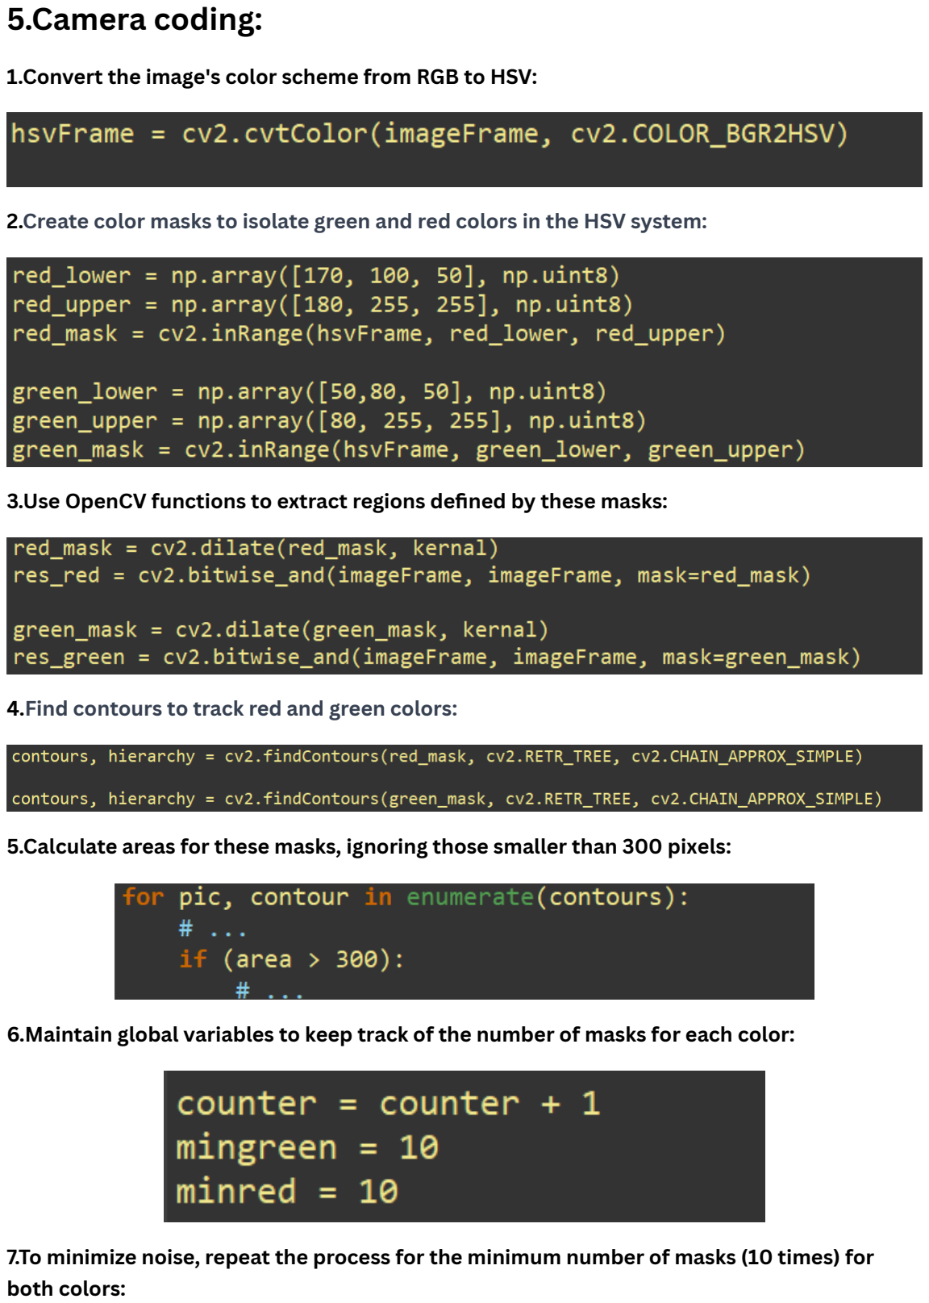
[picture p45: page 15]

1.Convert the image's color scheme from RGB to HSV:

2.Create color masks to isolate green and red colors in the HSV system:

3.Use OpenCV functions to extract regions defined by these masks:

4.Find contours to track red and green colors:

5.Calculate areas for these masks, ignoring those smaller than 300 pixels:

6.Maintain global variables to keep track of the number of masks for each color:

7.To minimize noise, repeat the process for the minimum number of masks (10 times) for both colors:

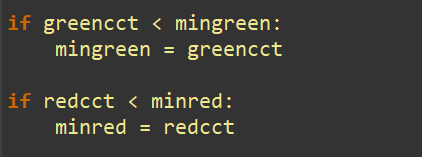
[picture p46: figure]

8.Establish a connection between the Raspberry Pi and an Arduino via the serial port, utilizing the serial library:

9.Send commands through the serial port to the ESP32 for it to execute appropriate actions.

# THE END KANNAN TEAM

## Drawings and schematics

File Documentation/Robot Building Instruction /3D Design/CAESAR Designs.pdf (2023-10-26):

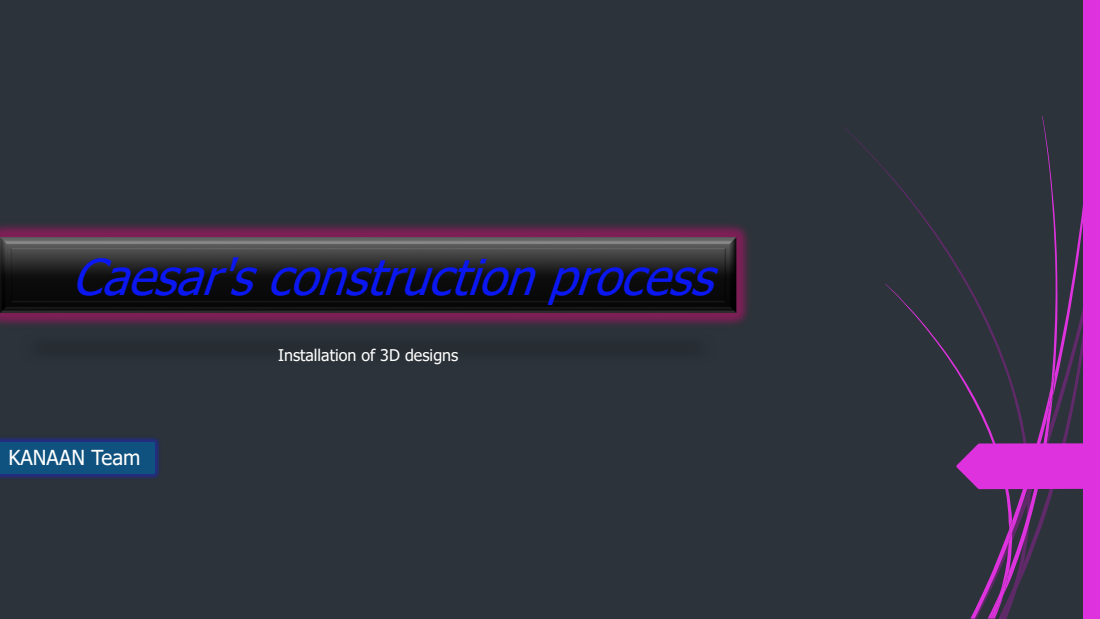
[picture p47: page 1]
KANAAN Team

Caesar's construction process

Installation of 3D designs

# 6 steps for installation

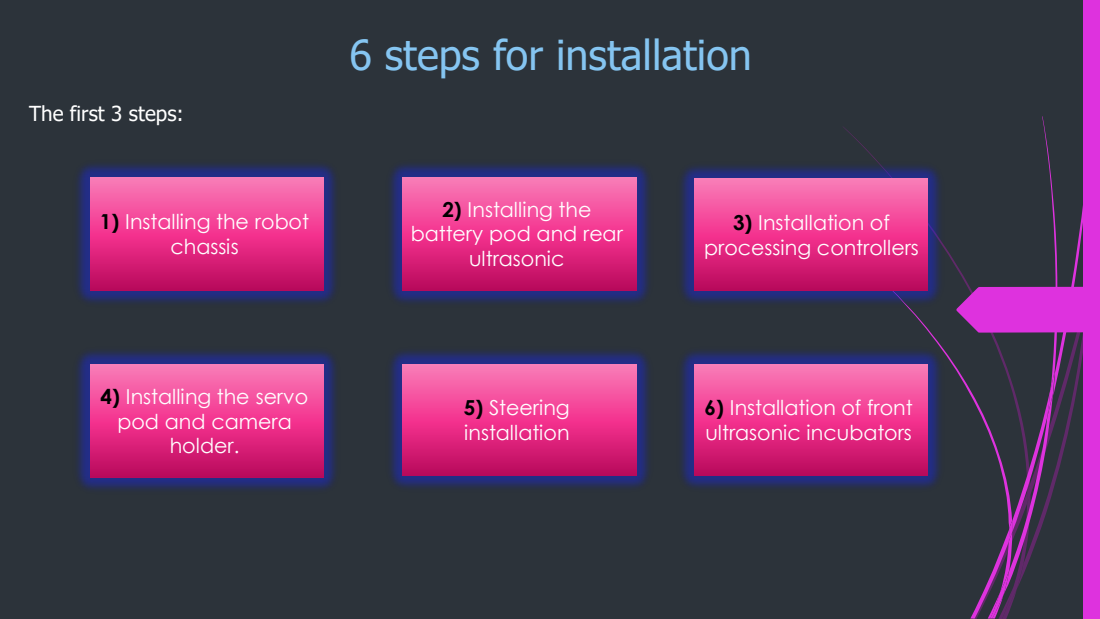
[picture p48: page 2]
chassis; 3) Installation of processing controllers; 5) Steering installation

The first 3 steps:

2) Installing the
battery pod and rear
ultrasonic

1) Installing the robot

4) Installing the servo
pod and camera
holder.

6) Installation of front
ultrasonic incubators

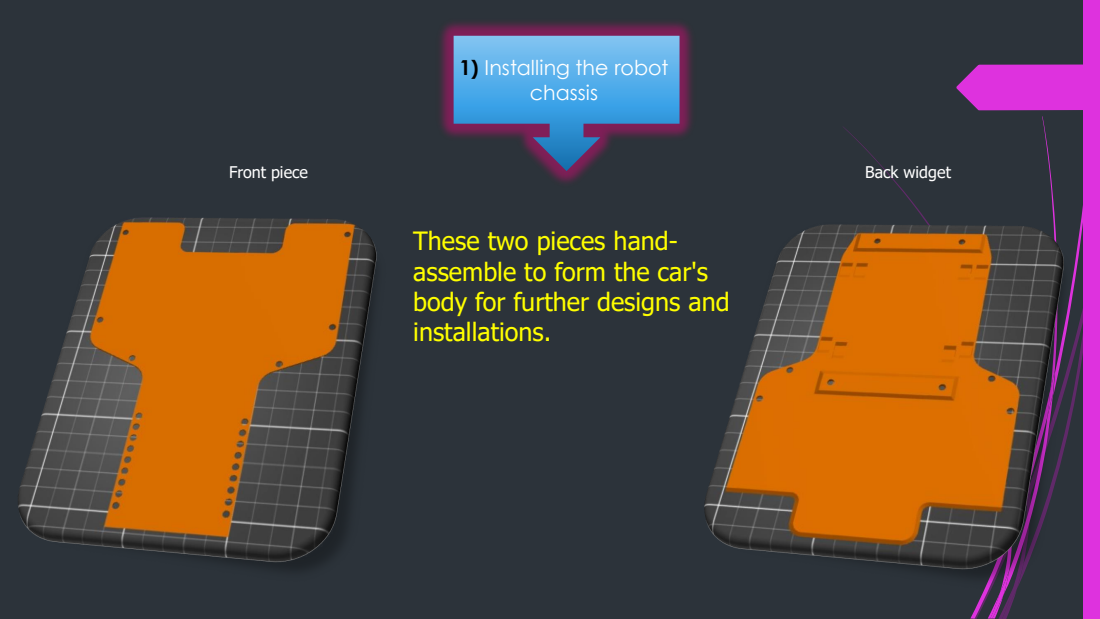
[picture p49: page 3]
Front piece; Back widget; chassis

1) Installing the robot

These two pieces hand-
assemble to form the car's
body for further designs and
installations.

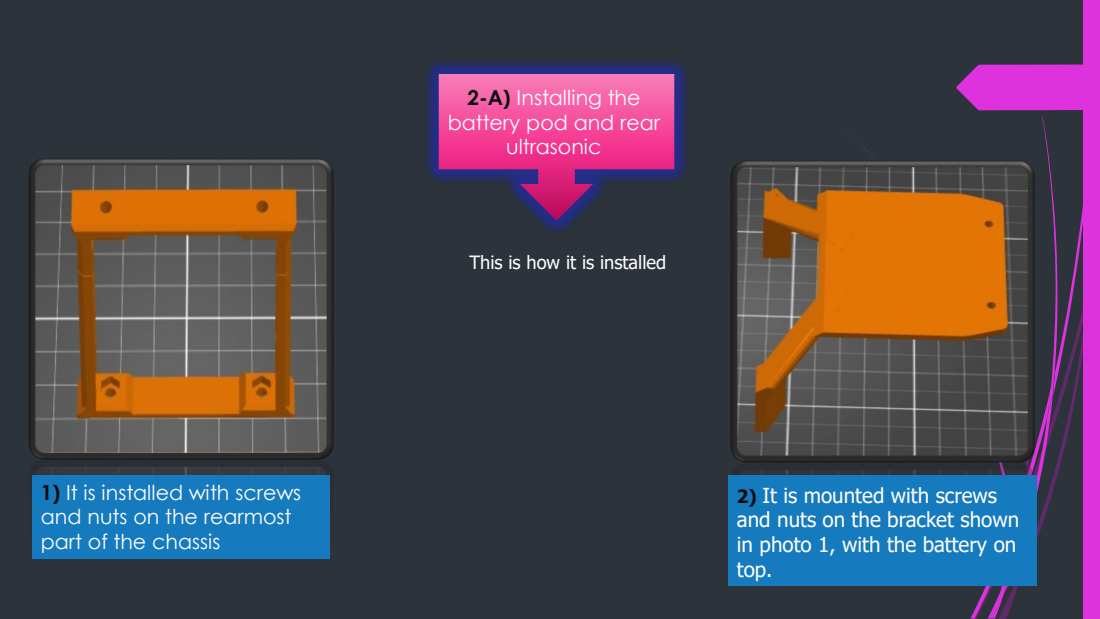
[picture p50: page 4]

2-A) Installing the
battery pod and rear
ultrasonic

This is how it is installed

1) It is installed with screws
and nuts on the rearmost
part of the chassis

2) It is mounted with screws
and nuts on the bracket shown
in photo 1, with the battery on
top.

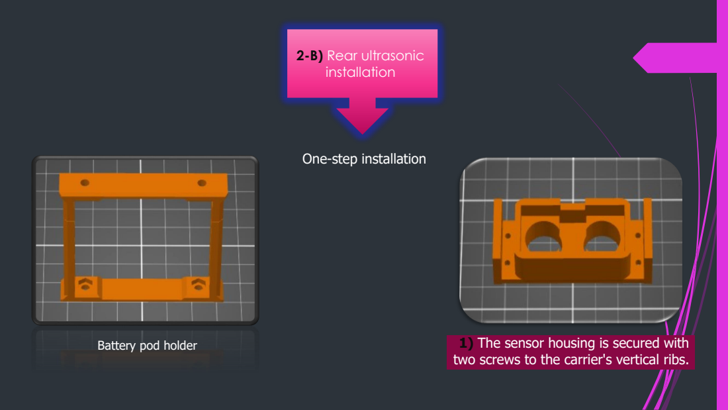
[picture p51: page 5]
2-B) Rear ultrasonic installation

One-step installation

Battery pod holder

1) The sensor housing is secured with
two screws to the carrier's vertical ribs.

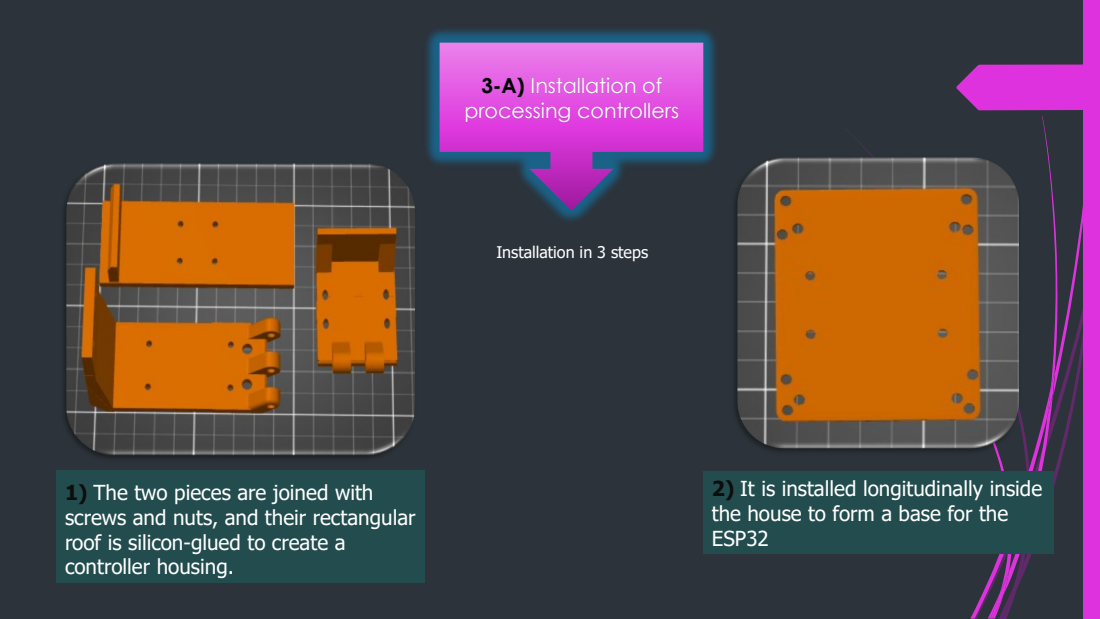
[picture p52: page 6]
3-A) Installation of processing controllers

Installation in 3 steps

2) It is installed longitudinally inside
the house to form a base for the
ESP32

1) The two pieces are joined with
screws and nuts, and their rectangular
roof is silicon-glued to create a
controller housing.

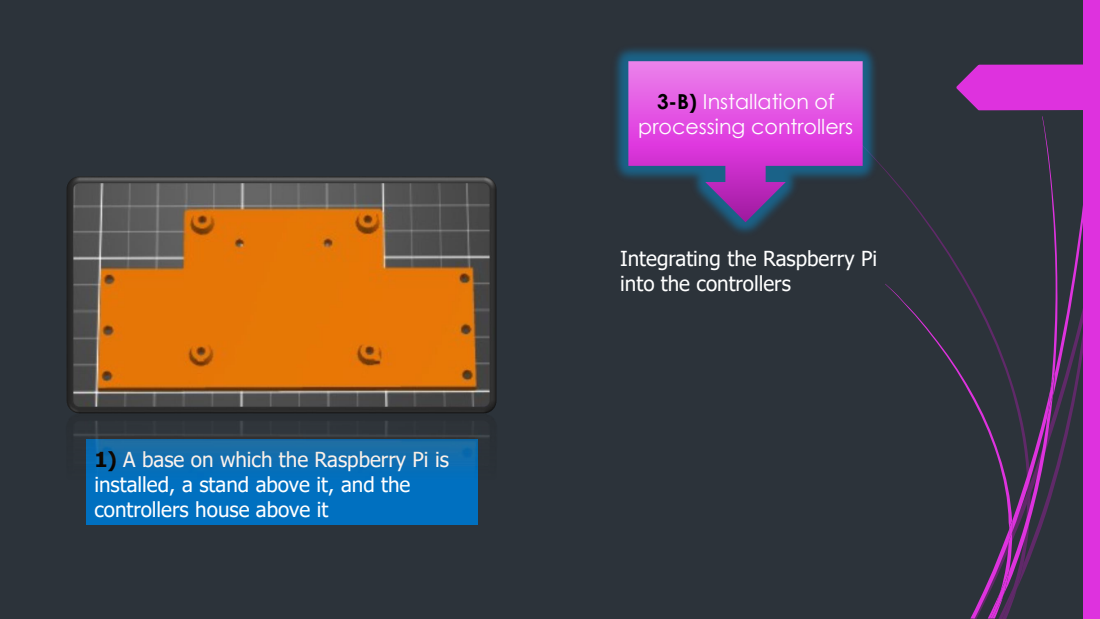
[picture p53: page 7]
3-B) Installation of processing controllers

Integrating the Raspberry Pi
into the controllers

1) A base on which the Raspberry Pi is
installed, a stand above it, and the
controllers house above it

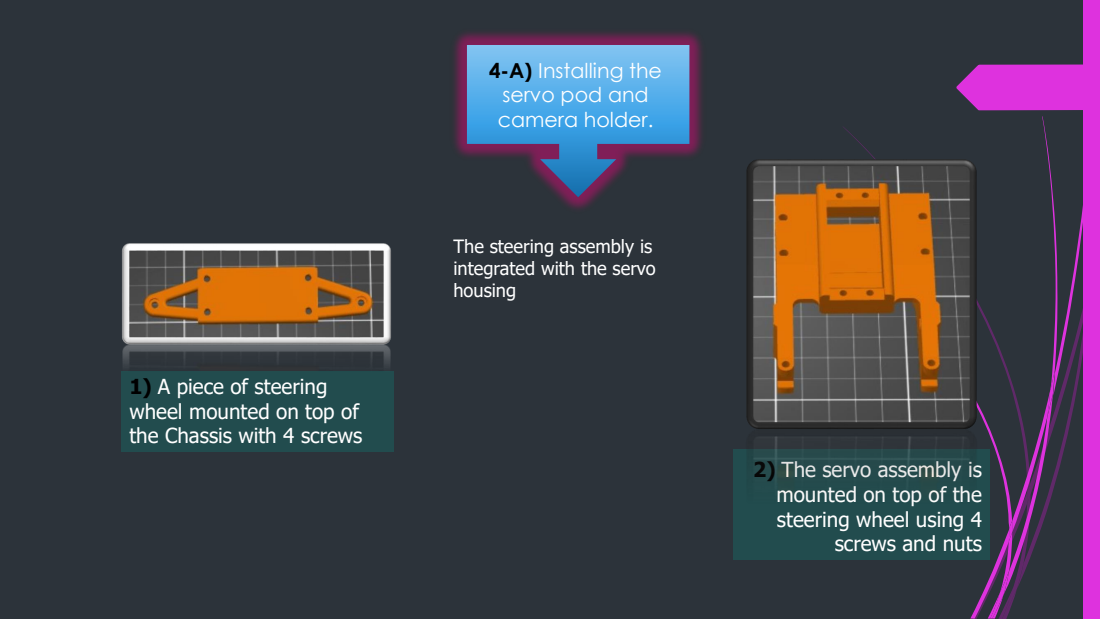
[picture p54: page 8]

4-A) Installing the
servo pod and
camera holder.

The steering assembly is
integrated with the servo
housing

1) A piece of steering
wheel mounted on top of
the Chassis with 4 screws

2) The servo assembly is
mounted on top of the
steering wheel using 4
screws and nuts

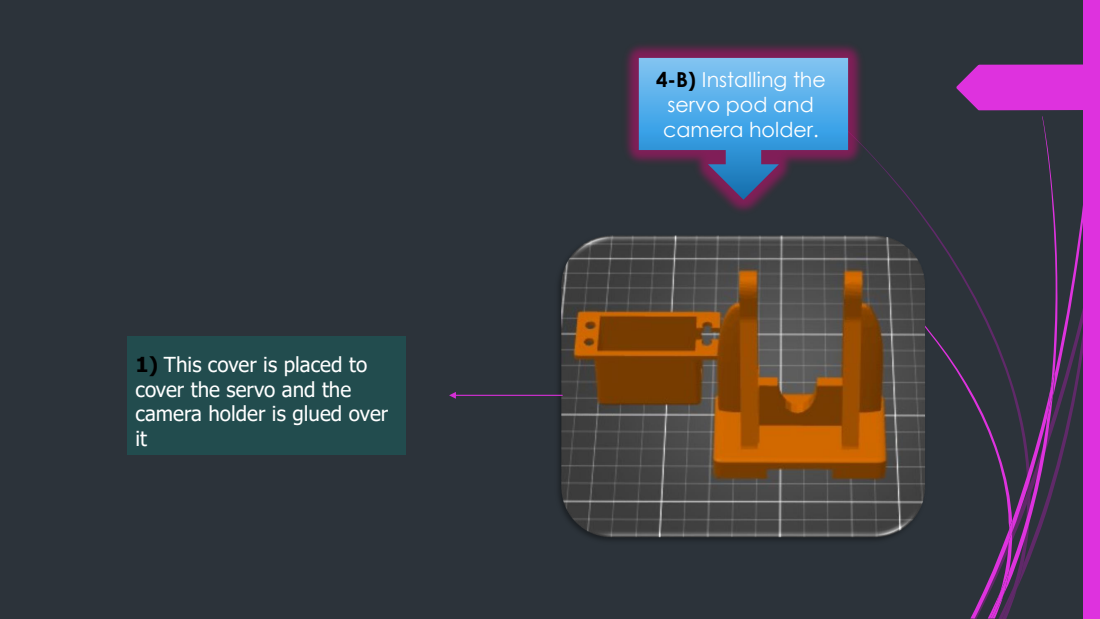
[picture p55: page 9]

4-B) Installing the
servo pod and
camera holder.

1) This cover is placed to
cover the servo and the
camera holder is glued over

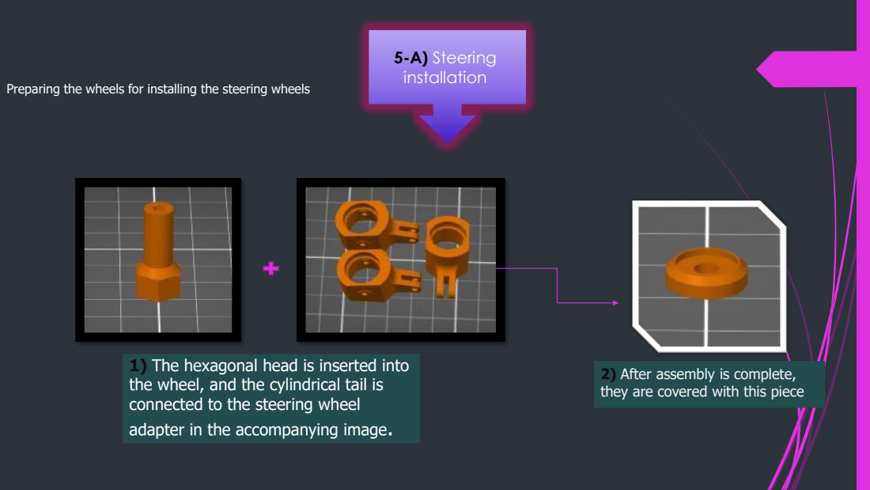
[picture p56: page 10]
5-A) Steering installation

Preparing the wheels for installing the steering wheels

1) The hexagonal head is inserted into
the wheel, and the cylindrical tail is
connected to the steering wheel
adapter in the accompanying image.

2) After assembly is complete,
they are covered with this piece

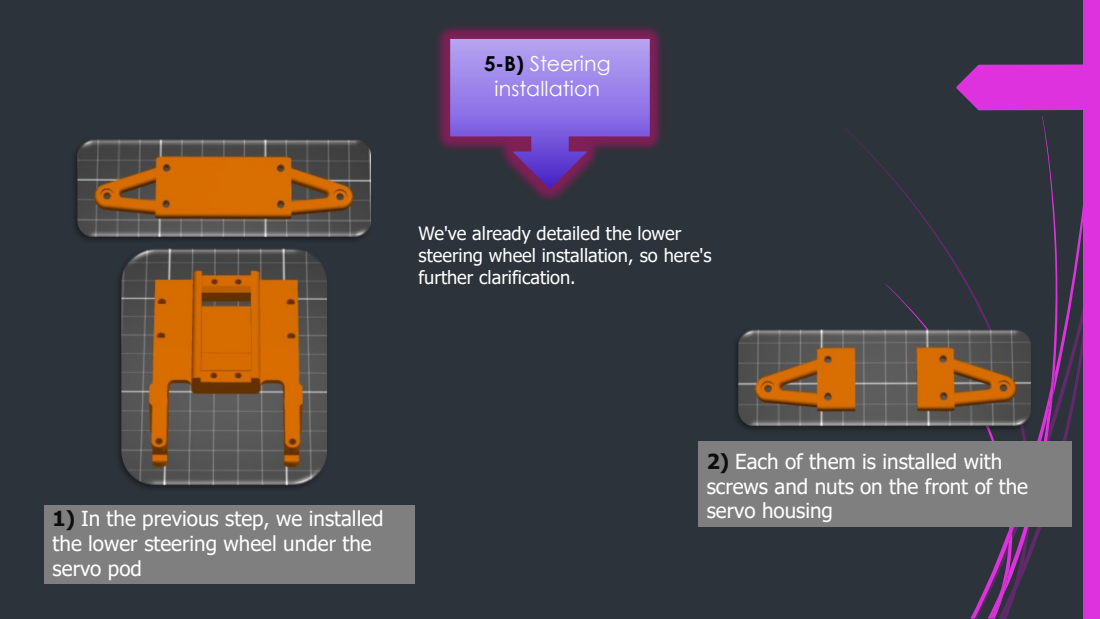
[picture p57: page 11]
5-B) Steering installation

We've already detailed the lower
steering wheel installation, so here's
further clarification.

2) Each of them is installed with
screws and nuts on the front of the

servo housing 1) In the previous step, we installed
the lower steering wheel under the
servo pod

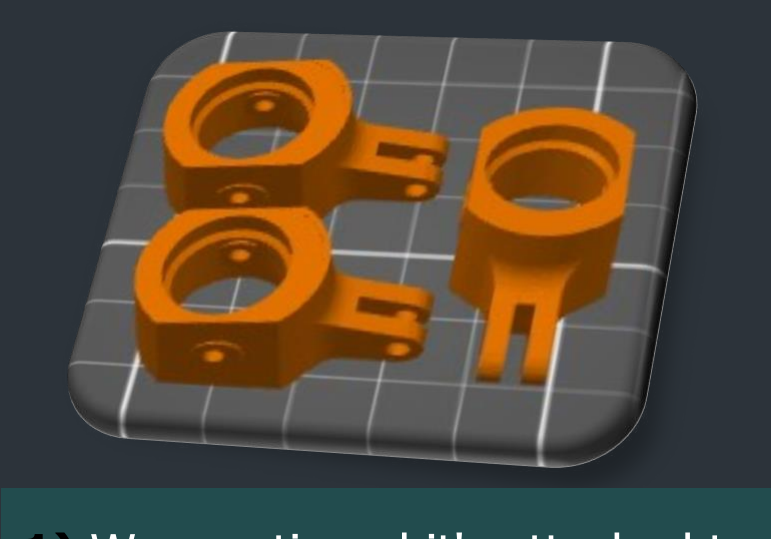
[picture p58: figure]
We previously explained about the motion vector, and now we explain its relationship with the motion engine; 2) The motion motor is attached to the motion guide and then connected in the middle to the servo motor to go right and left; 5-C) Steering installation

1) We mentioned it's attached to the handle using a hexagon-headed screw with a cap, secured top to bottom via a screw passing through the lower and upper string pieces, with an attached tongue for the movement engine


This picture shows the installation of
the fifth step and part of the fourth

servo slider: It is connected from the servo at
the bottom to the hole in the middle of the
motor with a spring


6) Installation of front
ultrasonic incubators

3) Back covers for the
ultrasonic incubator, right and
left, for consistency

1) The front ultrasonic
incubator, on both ends of
which the following two
incubators are installed

2) Ultrasonic incubator
right and left

THANK YOU; KANAAN TEAM

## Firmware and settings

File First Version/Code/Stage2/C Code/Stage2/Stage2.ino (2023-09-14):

#include"mode.h"
#include"Pins.h"
#include"RGBAndMode.h"
#include"DriveCar.h"
#include"Rotation.h"
#include"Ultrasonic.h"
#include"setSteering.h"
#include"Bluetooth.h"
#include"level1.h"
#include"level2.h"
unsigned long displayTime=0;

void setup() {
  
 
  Serial.begin(115200);
  initRGBAndMode();
  led(RED);
  initCar();
  init_mpu();
  initBT();
  initUltrasonic();
  initSteering();
  delay(500);
  readUltrasonic();
  initLevel1();
  motion_mode=STANDBY;
  checkLevel();
  driveTime=millis();
  
}

void loop() {
  
  //if(pidState){steering.write(steeringPID); }
  readUltrasonic();
  //debugUltrasonic();
  readAngle();
  readBT();
  checkStartButton();
  if (start){
    if(level){ doLevel2();}
    else{doLevel1();}
  }
  else{if(level){initLevel2();} else{initLevel1();} }

  //if(millis()-displayTime>200){debugUltrasonic();/* debugLevel1(); debugRotation();*/ displayTime=millis();}

}

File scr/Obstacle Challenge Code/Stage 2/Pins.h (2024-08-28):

#ifndef Pins_h
#define Pins_h
//Start and mode
#define START_BUTTON 39
#define MODE_KEY 36 // level1 or level2
//LED and colors
#define LED_RED 23
#define LED_BLUE 4
#define LED_GREEN 5



// for serial2
#define RXD2 16
#define TXD2 17

// for DC Motor Encoder
#define IN1 32
#define IN2 33
#define PWM 25
#define ENCODER_PIN 35
// for servo motor
#define STEERING_PIN 26


//#define VOL_MEASURE_PIN A2

// for ultra sonoc sinsors
#define ECHO_B 34
#define TRIG_B 27

#define ECHO_R 19
#define TRIG_R 18
#define ECHO_L 16
#define TRIG_L 17
#define ECHO_F 2       
#define TRIG_F 15

//#define LED_POWER 1
//#define LED_GREEN 1
//#define LED_RED 1


//#define START_BUTTON 1




#endif

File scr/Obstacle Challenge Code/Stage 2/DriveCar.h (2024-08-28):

#include <ESP32Servo.h>

#define CLOCKWIZE 0
#define ANTI_CLOCKWIZE 1
#define UNKNOWN_DIRECTION -1

#define STRAIGHT_STEERING 88
//#define STRAIGHT_STEERING 90
#define SPEED2 200
#define SLOW_SPEED2 190
                        
#define SLOW_SPEED3 175
#define SLOW_SPEED4 170  
#define SLOW_SPEED 160
//int initR,initL,initF;
int rounCounter=0;
int rotionDirection=UNKNOWN_DIRECTION;
bool pinAttached;
Servo steering;
int CurrentSteeringAng,steeringAngle;

// Setting PWM properties
const int freq = 40000;
const int pwmChannel = 2;
const int resolution = 8;
//int dutyCycle = 200;
volatile unsigned long encoder_count = 0;
int speed;
unsigned long driveTime = 0;

 void IRAM_ATTR isr() {
	encoder_count++;
}
void initCar() {

  speed=0;
  steering.attach(STEERING_PIN);
  //steeringAngle=89; //  >90 Rigth     <90 LEFT
  steering.write(STRAIGHT_STEERING);
  // put your setup code here, to run once:
 pinMode(PWM,OUTPUT);
 pinMode(IN1,OUTPUT);
 pinMode(IN2,OUTPUT);
 pinMode(ENCODER_PIN,INPUT);

attachInterrupt(ENCODER_PIN, isr, CHANGE);
   // configure LED PWM functionalitites
 ledcSetup(pwmChannel, freq, resolution);
  
  // attach the channel to the GPIO to be controlled
  ledcAttachPin(PWM, pwmChannel);
  pinAttached=true;
 digitalWrite(IN1,LOW);
 digitalWrite(IN2,LOW);
 speed=0;

  steering.setPeriodHertz(50);// standard 50 hz servo
	//myservo.attach(servoPin, 1000, 2000); // attaches the servo on pin 18 to the servo object

}
void setSteering(int ang){
   steering.write(ang);
}


void turnSteering(int angle ){
  if(CurrentSteeringAng>angle){
    for (int i=CurrentSteeringAng;i>=angle;i--){steering.write(i);delay(5);}
    }
  else{for (int i=CurrentSteeringAng;i<=angle;i++){steering.write(i);}delay(5);}
  CurrentSteeringAng=angle;
  }

void forward(int speed){
  //ledcAttachPin(PWM, pwmChannel);
  //analogWrite(PWM,speed);
  if(speed>254){if(pinAttached){ledcDetachPin(PWM); pinAttached=false;} digitalWrite(PWM,HIGH);}
  else{if(!pinAttached){ledcAttachPin(PWM, pwmChannel); pinAttached=true;}ledcWrite(pwmChannel, speed); } 
  digitalWrite(IN1,HIGH);
  digitalWrite(IN2,LOW);

}
void reverse(int speed){
  //Serial.println("Drive Revirce");
  //analogWrite(PWM,speed);
  if(speed>254){if(pinAttached){ledcDetachPin(PWM); pinAttached=false;} digitalWrite(PWM,HIGH);}
  else{if(!pinAttached){ledcAttachPin(PWM, pwmChannel); pinAttached=true;}ledcWrite(pwmChannel, speed); } 
  digitalWrite(IN1,LOW);
  digitalWrite(IN2,HIGH);
}



void stop(){
    digitalWrite(IN1,LOW);
    digitalWrite(IN2,LOW);
}

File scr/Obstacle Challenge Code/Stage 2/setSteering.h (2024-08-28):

#define INT_TIME 70000 //interrupt occured evry time (in micro sec.)
double dt;
bool pidState;
bool complementaryMode=false;
//volatile double last_time;
volatile int steeringPID;
volatile int steeringREvircePID;//setpoint
volatile int output=0;
hw_timer_t * timer = NULL;      //H/W timer defining (Pointer to the Structure)
double integral, previous = 0.0;

double kp, ki, kd;
volatile double setpoint;

double pid(double error)
{
  double proportional = error;
  integral += error * dt;
  double derivative = (error - previous) / dt;
  previous = error;
  double output = (kp * proportional) + (ki * integral) + (kd * derivative);
  return output;
}

void IRAM_ATTR setStiring_()
{
  
 // Serial.print("dt:"); Serial.println(dt);
 
  double actual;
  if(rotionDirection==ANTI_CLOCKWIZE || rotionDirection==UNKNOWN_DIRECTION){
    if(complementaryMode){
     // Serial.println("Complementary Mode");
      actual = (double)(87-rangeL);}
    else{actual = (double)rangeR;}
    
    }
  else if(rotionDirection==  CLOCKWIZE ){
    if(complementaryMode){actual = (double)(87-rangeR);}
    else{actual = (double)rangeL;}
    }
  if(actual!=0.0){
  //Serial.print("dist f b="); Serial.println(actual);
  double error = setpoint - actual;
  //Serial.print("setpoint="); Serial.println(setpoint);
  output =(int) pid(error);
  output=constrain(output, -4200,4200);
  output=map(output,-4200,4200,-20,20);
  output=constrain(output, -10,10);


  if(rotionDirection==ANTI_CLOCKWIZE || rotionDirection==UNKNOWN_DIRECTION){ 
      steeringPID=STRAIGHT_STEERING-output;
      steeringREvircePID=STRAIGHT_STEERING+output;
      }
  else if(rotionDirection==  CLOCKWIZE ){
     steeringPID=STRAIGHT_STEERING+output;
     steeringREvircePID=STRAIGHT_STEERING-output;
  }
}

}

void initSteering()
{ complementaryMode=false;
  pidState=false;
  //kp = 280.0;
  kp = 700.0;
  ki = 0.0;
  kd = 23.0;
  dt=(double)INT_TIME/1000000;
  timer = timerBegin(0, 80, true);             // timer 3, prescalar: 80, UP counting
  timerAttachInterrupt(timer, &setStiring_, true);   // Attach interrupt
  timerAlarmWrite(timer, INT_TIME, true);     // Match value= 70000 for 70 msec. delay.
  timerAlarmEnable(timer);                 // Enable Timer with interrupt (Alarm Enable)
 
 // setpoint = 15.0;
  steering.write(STRAIGHT_STEERING);
 
}
////////////////////////////////////////////////////


void driveBetween(){
  // setStiring_();
  }

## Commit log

2023-10-12 Arrange old folders in the First Version folder
    [Basic_Wheel_01_Nut.stl, Battary Holder1.stl, Body_L.stl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]
2023-10-17 Edit GitHub folders
    [Basic_Wheel_01_Nut.stl, Battary Holder1.stl, Body_L.stl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]
2023-10-17 edit folder
    [Basic_Wheel_01_Nut.stl, Battary Holder1.stl, Body_L.stl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]
2023-10-22 Add Folders
    [Basic_Wheel_01_Nut.stl, Battary Holder1.stl, Body_L.stl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]
2023-10-22 Move to Folder
    [Smooth Waasa.stl]
2023-10-25 Add .stl
    [ESP32HolderF (2).stl, FinalUltra (8).stl, Kanaan_Back (1).stl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]
